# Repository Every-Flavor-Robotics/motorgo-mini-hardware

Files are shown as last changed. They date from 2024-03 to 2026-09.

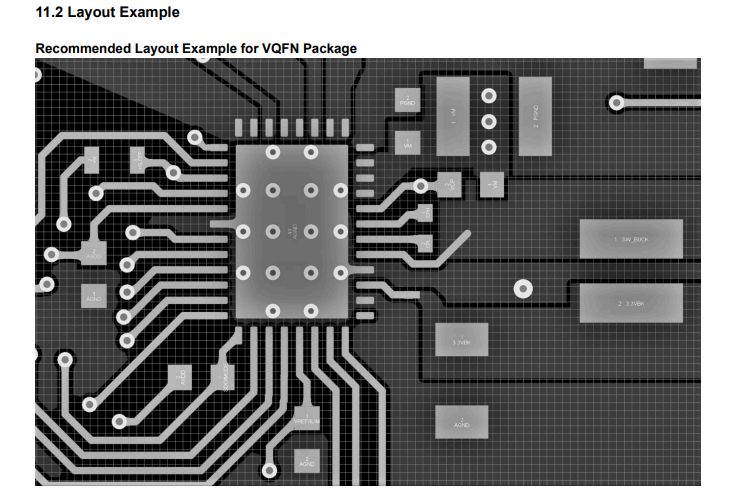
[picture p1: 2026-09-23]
motorgo-gimbus/Pasted image 20250722134249.png

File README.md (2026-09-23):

# motorgo-mini-hardware
## This repo is the home of the hardware revisions for the MotorGo-mini!
### This is a condensed and specialized version of the MotorGo-Mini, featuring:
- Esp32s3 based system, compatible with ESPIDF or Arduino
- Wifi + BT
- Single channel of motor control
- Integrated MT6701 magenetic encoder on back of board
- DRV8316 TI motor controller with low-side current sense
- 3A continous 8A peak FOC motor controls
- RGB LED indicator
- USB PD x2 with power ORing to protect power sources
- 6P JST PH input: 5V-20V
- CAN bus over USB-C (experimental use of sideband signals in USB 3.2+)

### Its still in development, particularly USBPD seems to be malfunctioning.  But checkout the schematics, renders, use example, and photos of the real board!
### Full board Render:
Gimbusv1r2_straight_on

### Example board + motor + rendering:
Gimbusv1r2_exoploded_viewpng

### Top Level Schematic (full color):


### USB Module Sub-Schematic:


### DRV8316 Sub-Schematic:


### RGB indicator:


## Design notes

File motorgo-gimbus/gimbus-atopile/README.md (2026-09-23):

# gimbus

Turn a gimbal motor into a powerful CAN-bus enabled servo with simpleFOC and ESP32

Created by Alexchunlin <alexchunlin@everyflavorrobotics.com>

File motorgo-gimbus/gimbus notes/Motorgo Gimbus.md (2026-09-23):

## This project is to make a small, bussed servo controller compatible with the motorgo ecosystem.
---
### Objectives and context:
1. Many of our previous boards are designed for maximum versatility - but this board is specifically for a small selection of motors.  **Gimbal motors** around the 45mm diameter. 
2. There is an explicit intent to design this board for use in the KineThreads project that is a part of Vivian Shen's research in HRI.  The KineThread project is an exosuit that enables VR and AR haptics by applying forces to the exosuit's joints via tensioned threads.  Each motor on the suit controls a spool of thread and the tension is currently roughly approximated with voltage to each motor.  This project should be able to provide **current control** - increasing the resolution and consistency of tension on the suit.
3. We have not been able to get **USB-PD** reliably working on our boards before and this project will be a test for us in adding that to our ecosystem.
4. Creating this project in atopile will be a new workflow and this relatively simple project should be a good testing ground for this new tool!

### Requirements:
- SimpleFOC compatibility
- Esp32 based for compatibility to the motorgo ecosystem
- Motor controls with voltage range of up to 24V
- Current control on the motor phases, low side or inline is acceptable
- board size must fit within 45mm diameter circle and its maximum height is 10mm
- CAN bus and two physical ports so that a chain of actuators can be made
- USB-PD 5a 20v
- 4 layer board stackup with complete ground plane
- 1 power indicator led in red, 1 motor enabled indicator led in blue, and one neopixel rgb led for  status indication
- two tactile switches for boot and reset 
- magnetic encoder on center of board, opposite side of esp32
- 3 phase motor wire output

### Component Selection
- **Microcontroller: ESP32-S3-WROOM-N8**
	**Reasoning:** A powerful and cost-effective module with integrated Wi-Fi and Bluetooth. It has all the necessary hardware peripherals for this project, including a native CAN controller (TWAI), USB OTG for programming, SPI, and I2C.

- **Motor Driver: DRV8316CR**
	-**Reasoning:** A highly integrated 3-phase motor driver that simplifies the design by including FETs and current sense amplifiers. It supports up to 35V and communicates via SPI for configuration and fault reporting. Its internal buck regulator will not be used to power the ESP32.

- **Buck Regulator: XL1509-3.3E1**
	- **Reasoning:** This switching regulator was chosen to provide a stable 3.3V rail for the entire board. It accepts an input voltage of up to 40V, providing a safe margin, and can deliver up to 2A, which is more than sufficient for the ESP32's peak current draw during radio use.
	- **Implementation Note:** As a non-synchronous converter, this part requires an external Schottky diode for proper operation.

- **USB Power Delivery: HUSB238A-BB001-QN16R (x2)**
	- **Reasoning:** A dedicated USB-PD controller that simplifies power negotiation over USB-C. The design uses two of these ICs, one for each port, to allow for up to 20V @ 5A power delivery. The outputs will be fed into a common power rail via ideal diodes to prevent back-powering.

- **CAN Transceiver: TJA1051T**
	- **Reasoning:** A standard, reliable, 3.3V-compatible CAN transceiver.
	- **Implementation Note:** Each board will feature a 120Ω termination resistor selectable via a jumper or DIP switch. This allows any board to be configured as a termination point if it is at the physical end of the daisy-chain.

- **Encoder: Magntek MT6701**
	- **Reasoning:** A high-resolution magnetic encoder (16,384 counts/rev) compatible with existing software. It communicates via I2C. The MODE pin will be tied to VDD to select I2C operation.

- **USB-C Connectors: XKB_Connectivity_U262_241N_4BV64 (x2)**
	- **Reasoning:** Standard USB-C connectors chosen for their high density and the availability of robust, full-featured cables.

## Circuit & Logic Design
**The board will feature two identical USB-C ports (LEFT and RIGHT) to allow for daisy-chaining of power and data.**

- **Power Delivery:** The CC and VBUS lines from each port are routed to their own dedicated STUSB4500 PD controller.
- **USB Programming MUX:** The D+/D- lines from both ports are routed to a FSUSB42 MUX to allow programming from either port.
- **Switching Logic:** The VBUS from each port will be used to automatically control the MUX's select pin. To prevent a short circuit, a logic gate (e.g., an OR or NOR gate) will be used to combine the signals, creating a priority system where one port takes precedence if both are connected.
- **CAN Bus Topology:** The board will be wired as a pass-through node.
	- The SSTX+/- lines from the LEFT port will be routed directly to the SSTX+/- lines of the RIGHT port.
	- The CAN transceiver's CANH and CANL pins will "tap into" this main bus line with the shortest possible traces.
	- This design maintains a single, continuous bus line through the device, minimizing stubs and ensuring high signal integrity.

### Scratch notes and dev todos:
==**Links to stuff:**==
 > usbc cables: https://www.amazon.com/dp/B0CS64PLTC/?
 > adafruit can dev: https://www.adafruit.com/product/5708?
	 TJA1051T/3/1J
	 > ![[Pasted image 20250721132601.png]]
 > usbc dev: https://www.digikey.com/en/products/detail/stmicroelectronics/EVAL-SCS001V1/10231579?
 > ESP32s3 Tech Ref Manual: https://www.espressif.com/sites/default/files/documentation/esp32-s3_technical_reference_manual_en.pdf
 > ESP32s3 module datasheet: https://www.espressif.com/sites/default/files/documentation/esp32-s3-wroom-1_wroom-1u_datasheet_en.pdf
 > DRV8316 block diagram application:
 > ![[Pasted image 20250722132813.png]]
 ![[Pasted image 20250722134537.png]]
 > ![[Pasted image 20250722134249.png]]

Impedance control for jlc stackup: 90 ohm and 120 ohm lines (CAN and USB)
![[Pasted image 20250723125023.png]]
- CAN TX needs 5v supply - so i had to add a boost conv off of the 3v3 rail, luckily i had designed a good headroom on the 3v3 - here's what I'm adding based on the input current calc:
	- **Power Out:** Pout=5V×70mA=350mW
	- **Power In:** Pin=ηPout=0.85350mW≈412mW
	- **Input Current:** Iin=VinPin=3.3V412mW≈125mA
	- =) C490380, the DIODES PAM2401YPADJ for simplicity even though its overkill

For usb pd protection / power ORing chip is the lm73100 
- VIN(UV) = 1.22V * (270kΩ + 100kΩ) / 100kΩ = 4.514V
- VIN(OV) = 1.22V * (160kΩ + 10kΩ) / 10kΩ = 20.74V
- isense from ideal diode to get board current:
	- R_imon = V_imon /G* I_imon 
		- R_imon = 1.65 Kohm resistor
		- set ESP32 to ADC_ATTEN_DB_6 (0mv -1750mv)
	- zener diode choose for 1.8v to clamp spikes

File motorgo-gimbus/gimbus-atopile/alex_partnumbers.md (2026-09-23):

encoder : MT6701QT-STD - C2913974
mcu : ESP32-S3-WROOM-1-N8 - C2913198
usbc thru : U262-241N-4BV64 - C388660
motor driver: DRV8316CRRGFR - C5447274
3v3 buck : SXL1509-3.3E1 - C33960106
6p jstph : S6B-PH-SM4-TB(LF)(SN) - C2845446
CAN TX : TJA1051TK/3/1J - C2875699
USB MUX: FSUSB42UMX - C42370490
usbpd : STUSB4500QTR - C2678061
inductor_buck : C2929441
schottkey : C8598
schottky_tiny : C2923958

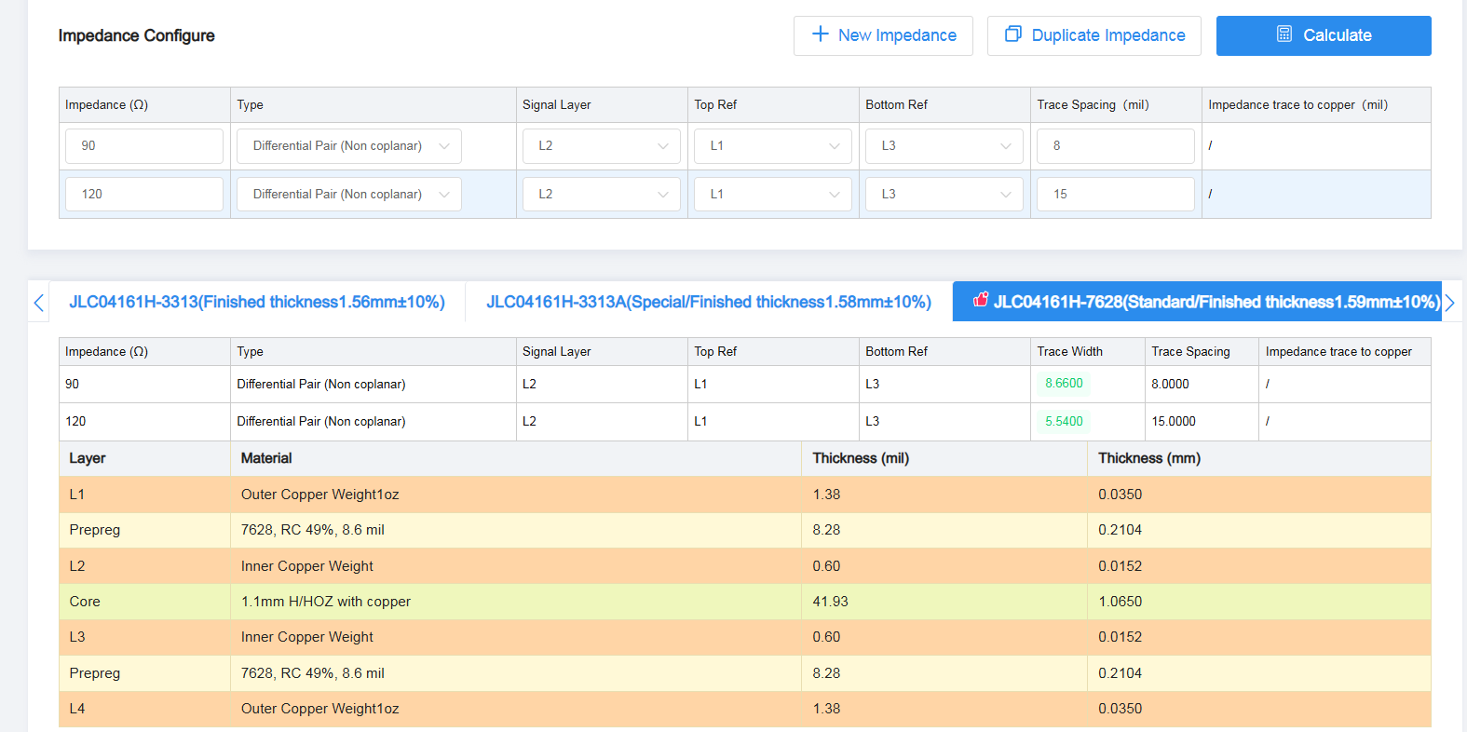
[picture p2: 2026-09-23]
motorgo-gimbus/Pasted image 20250723125023.png

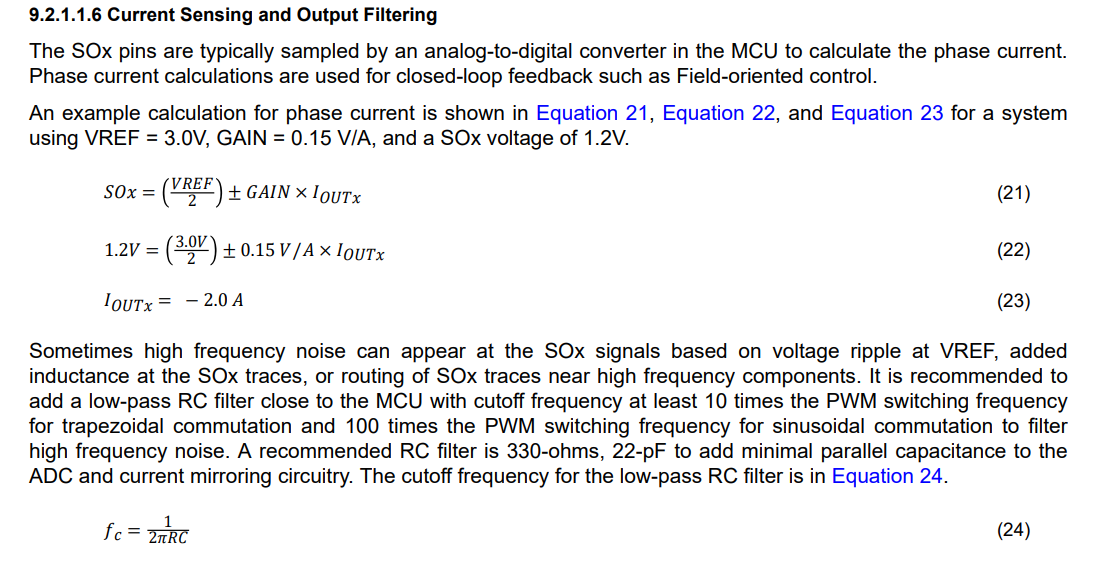
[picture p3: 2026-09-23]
motorgo-gimbus/Pasted image 20250722134537.png

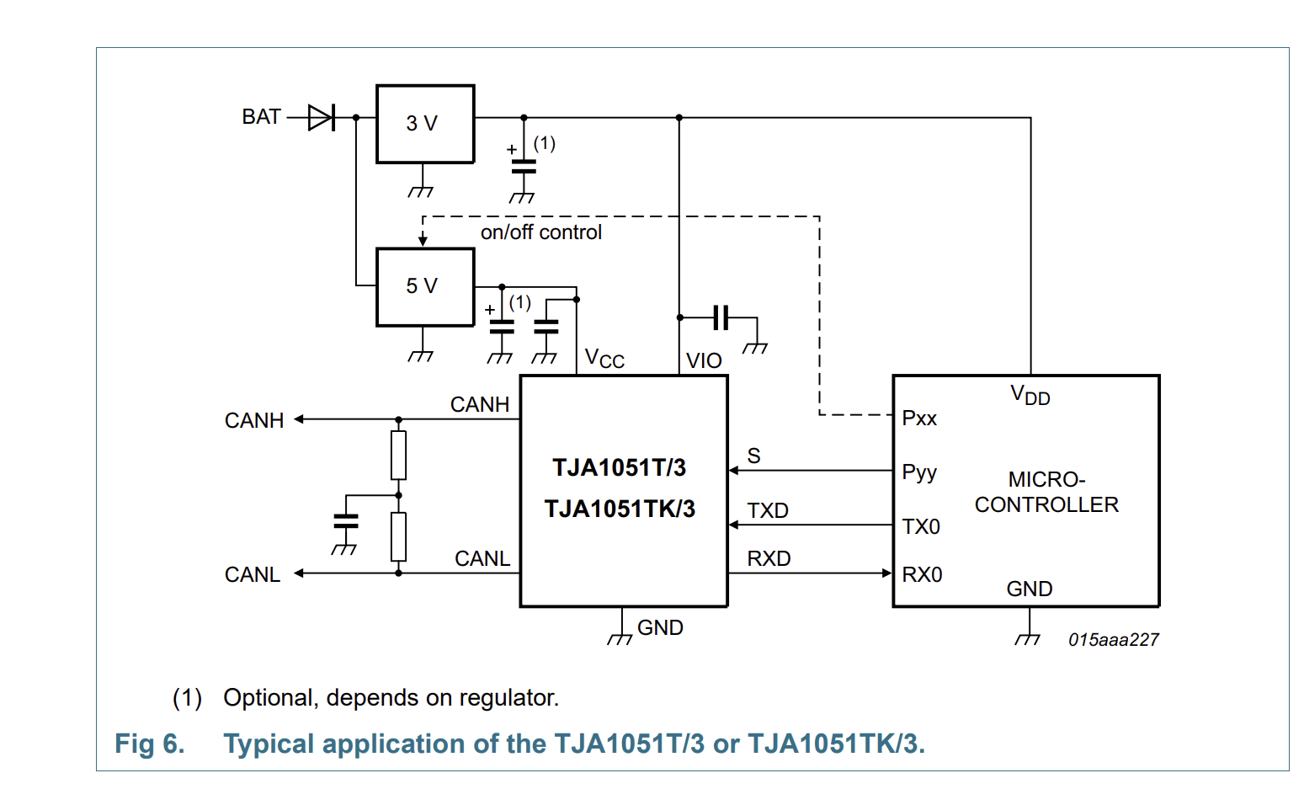
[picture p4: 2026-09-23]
motorgo-gimbus/gimbus notes/Pasted image 20250721132601.png

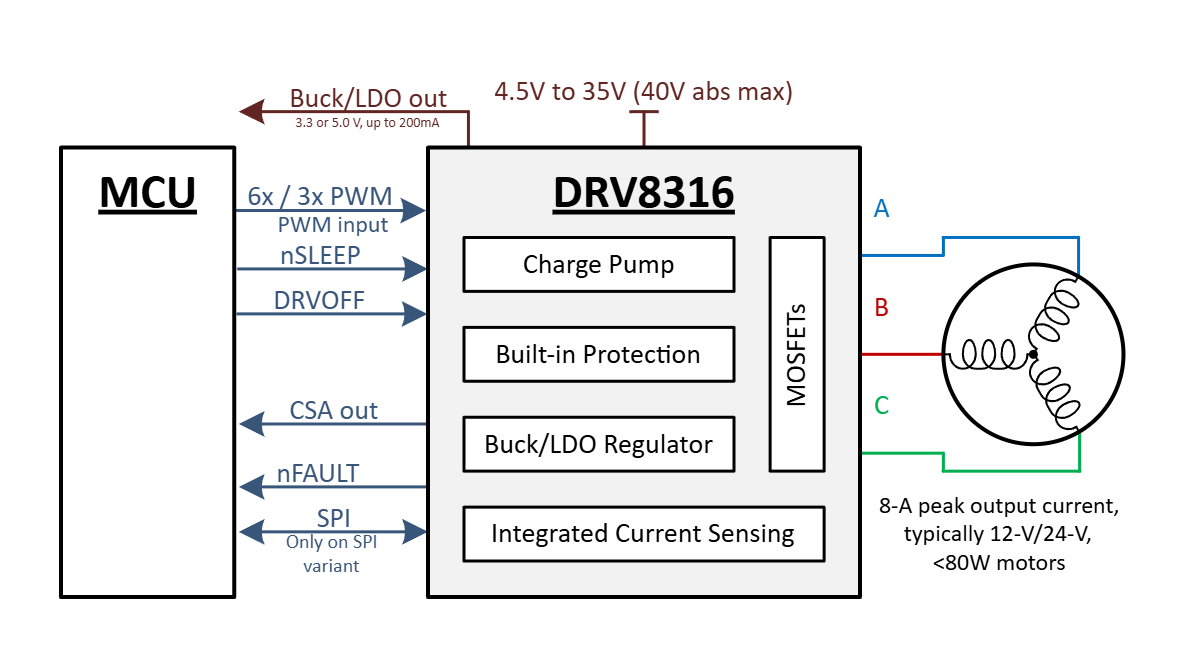
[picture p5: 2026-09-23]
motorgo-gimbus/Pasted image 20250722132813.png

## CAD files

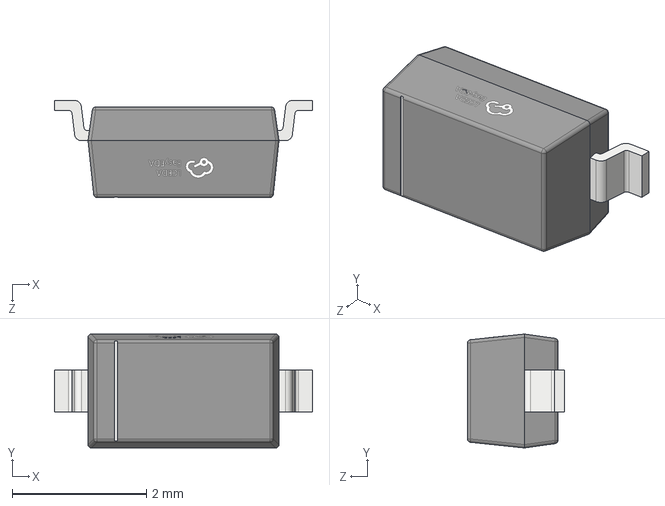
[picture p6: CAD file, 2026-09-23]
motorgo-gimbus/gimbus-atopile/parts/Changjiang_Electronics_Tech_B5819W_SL/SOD-123_L2.7-W1.6-LS3.7-RD-1.step
3.85 x 1.70 x 1.45 mm

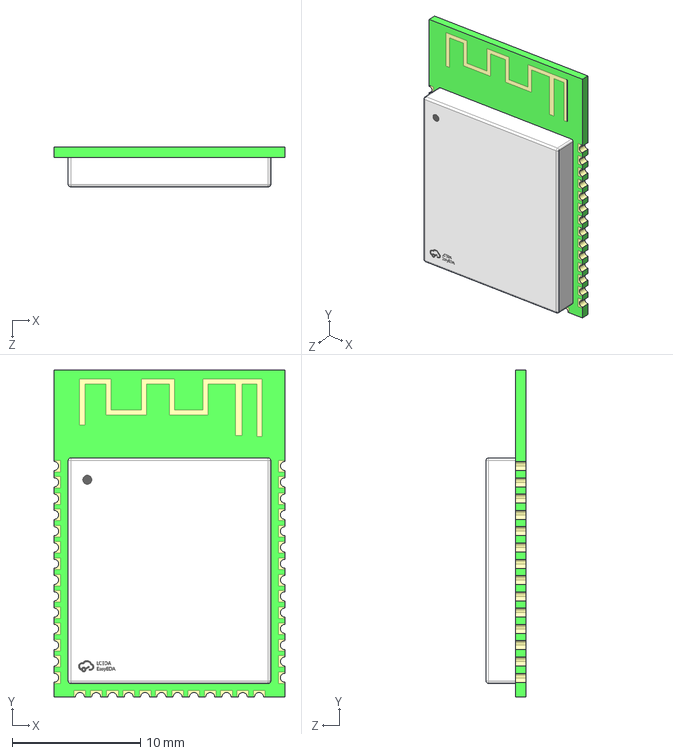
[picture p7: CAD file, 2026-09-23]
motorgo-gimbus/gimbus-atopile/parts/Espressif_Systems_ESP32_S3_WROOM_1_N8/WIFIM-SMD_ESP32-S3-WROOM-1-N8.STEP
18.0 x 25.5 x 3.12 mm

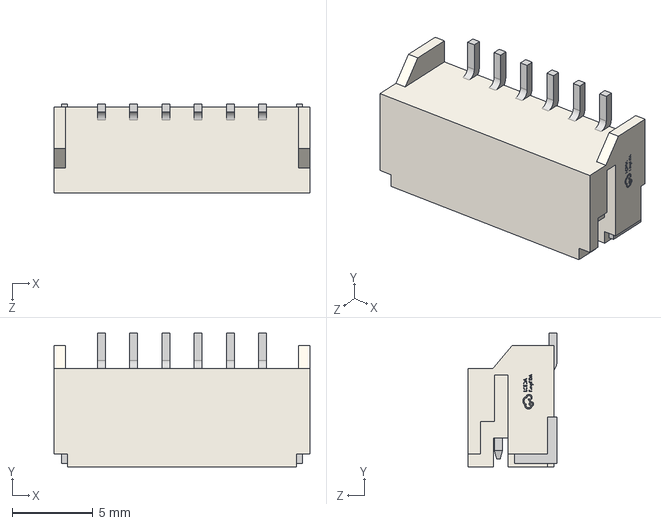
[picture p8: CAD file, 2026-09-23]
motorgo-gimbus/gimbus-atopile/parts/HCTL_HC_PH_6AWT/CONN-SMD_6P-P2.00_HCTL_HC-PH-6AWT.step
15.9 x 8.30 x 5.55 mm

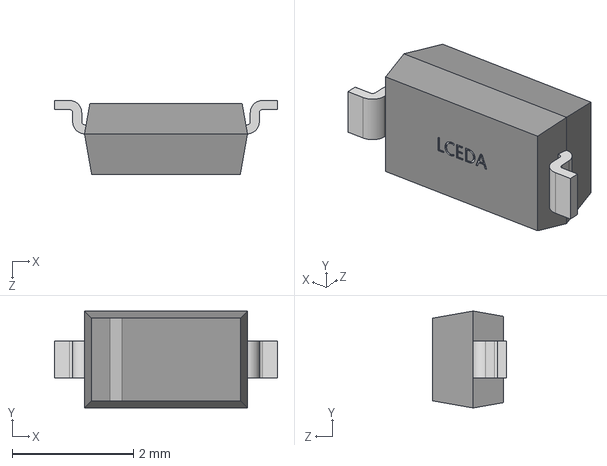
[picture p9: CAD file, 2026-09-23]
motorgo-gimbus/gimbus-atopile/parts/Jiangsu_Changjing_Electronics_Technology_Co___Ltd_DSS34/SOD-123_L2.8-W1.8-LS3.7-RD.STEP
3.68 x 1.60 x 1.22 mm

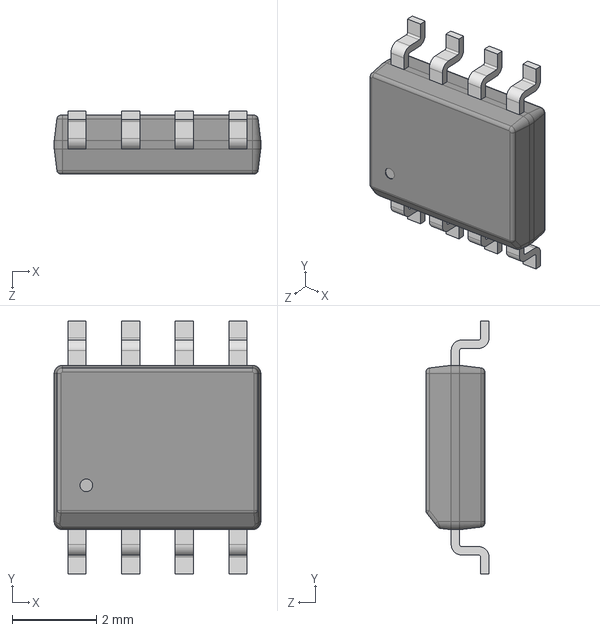
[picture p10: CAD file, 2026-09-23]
motorgo-gimbus/gimbus-atopile/parts/JSMSEMI_SXL1509_3_3E1/SOP-8_L4.9-W3.9-P1.27-LS6.0-BL-1.STEP
4.90 x 6.00 x 1.50 mm

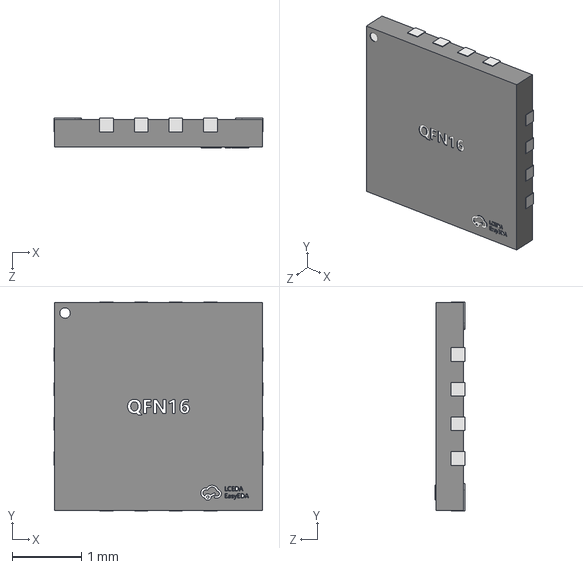
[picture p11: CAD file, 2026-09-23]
motorgo-gimbus/gimbus-atopile/parts/Magn_Tek_MT6701QT_STD/QFN-16_L3.0-W3.0-H0.9-P0.50.step
3.02 x 3.02 x 0.43 mm

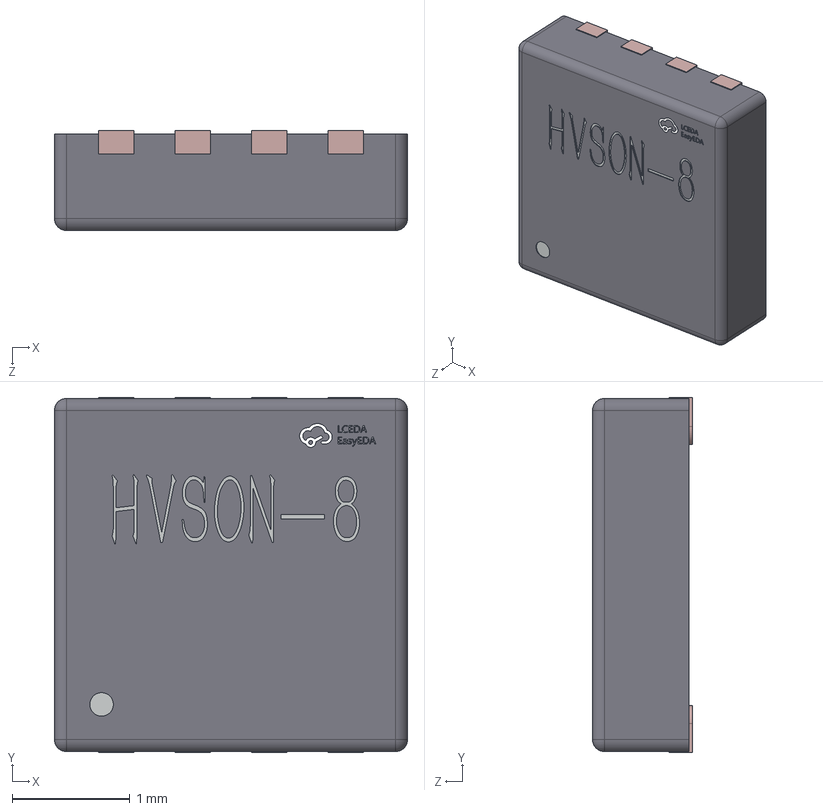
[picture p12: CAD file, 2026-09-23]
motorgo-gimbus/gimbus-atopile/parts/NXP_Semicon_TJA1051TK_3_1J/HVSON-8_L3.0-W3.0-H0.85-P0.65-BL-EP.step
3.00 x 3.02 x 0.851 mm

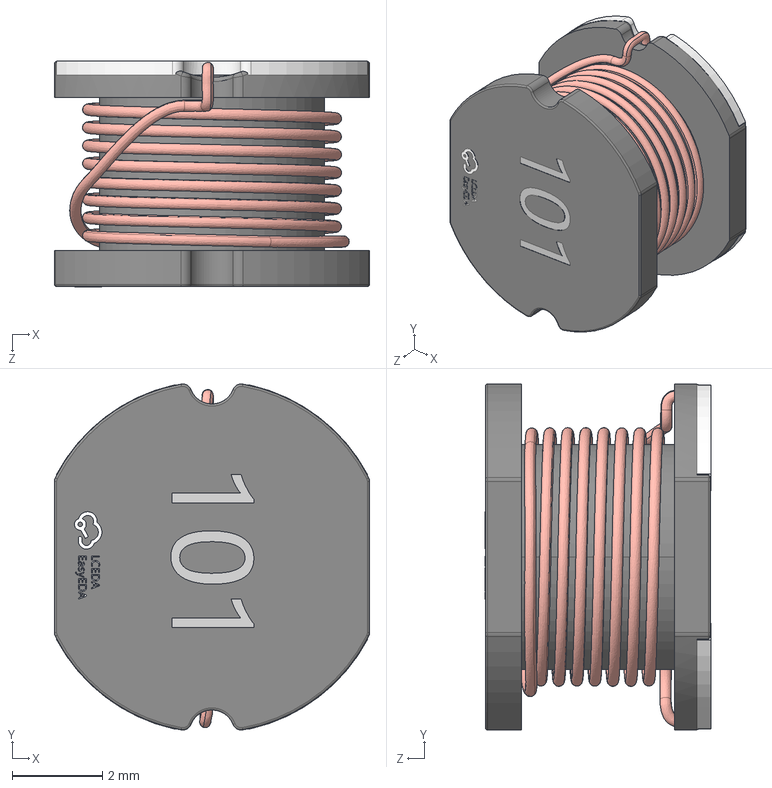
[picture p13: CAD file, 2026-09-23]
motorgo-gimbus/gimbus-atopile/parts/SHOU_HAN_CY75_47UH/IND-SMD_L7.8-W7.0-H5.0-0.705.step
7.00 x 7.68 x 5.02 mm

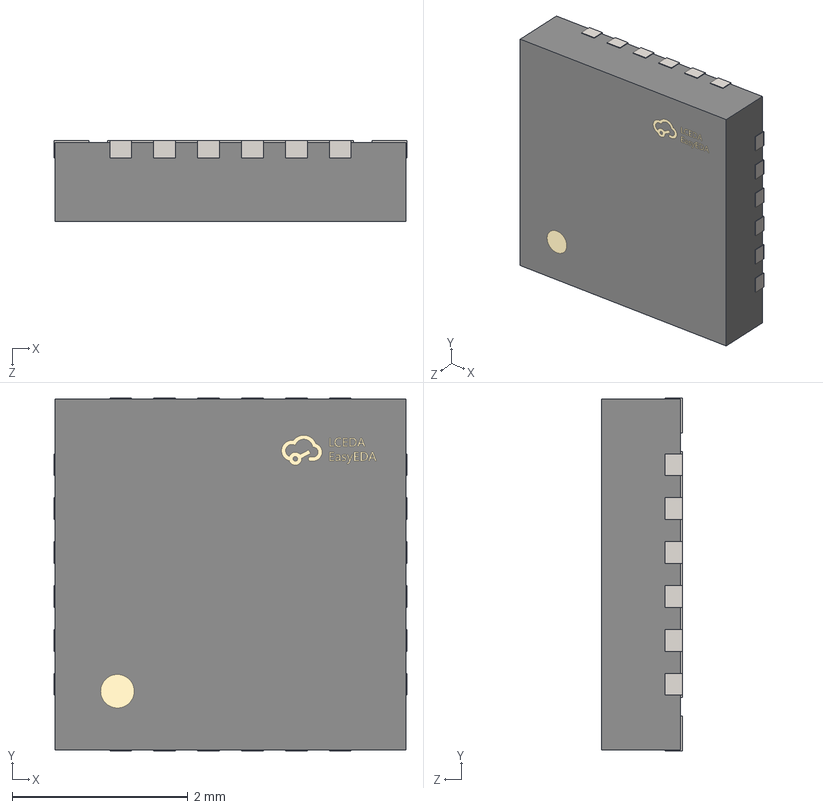
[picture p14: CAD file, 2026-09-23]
motorgo-gimbus/gimbus-atopile/parts/STMicroelectronics_STUSB4500QTR/57.STEP
4.02 x 4.02 x 0.92 mm

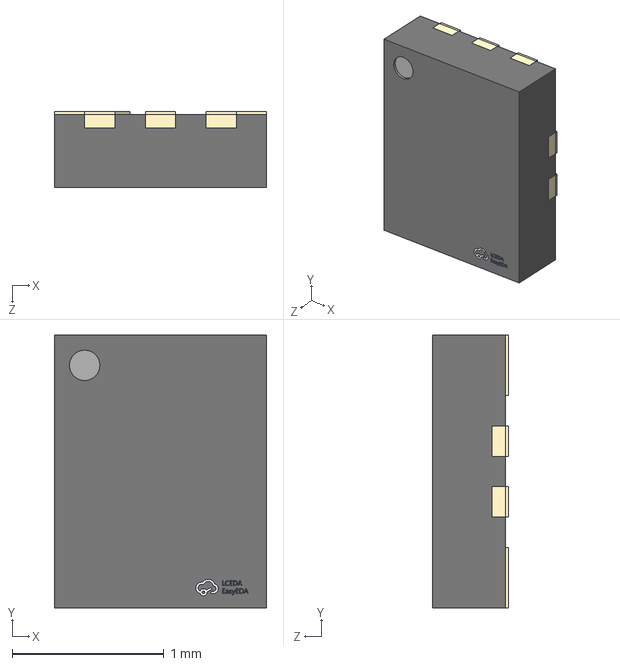
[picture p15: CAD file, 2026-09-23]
motorgo-gimbus/gimbus-atopile/parts/TECH_PUBLIC_FSUSB42UMX_TP/XQFN-10_L1.8-W1.4-H0.5-P0.40-TL.step
1.40 x 1.80 x 0.501 mm

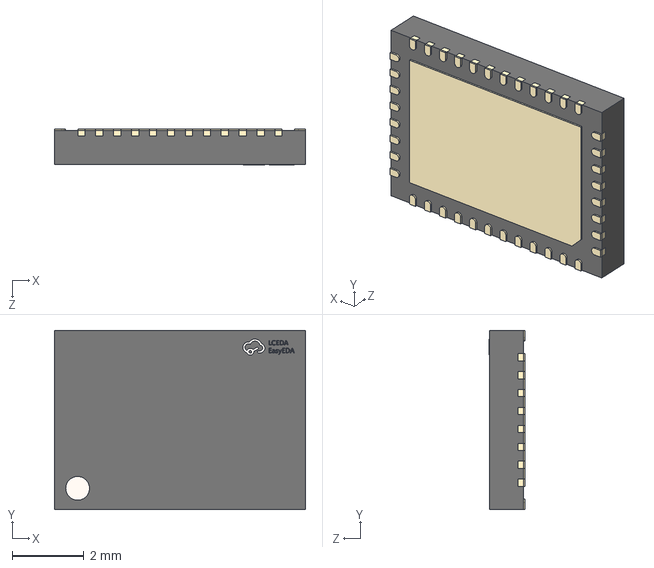
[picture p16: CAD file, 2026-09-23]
motorgo-gimbus/gimbus-atopile/parts/Texas_Instruments_DRV8316CRRGFR/VQFN-40_L7.0-W5.0-P0.50-BL-EP5.7.STEP
7.00 x 5.00 x 1.01 mm

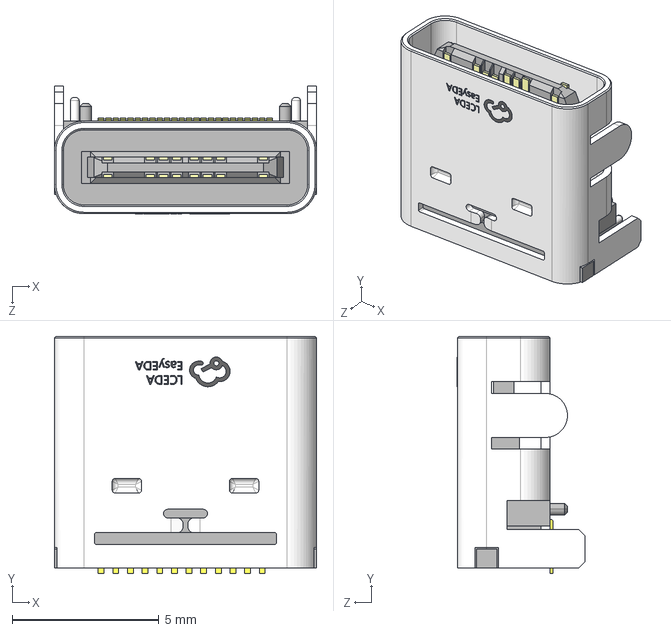
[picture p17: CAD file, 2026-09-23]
motorgo-gimbus/gimbus-atopile/parts/XKB_Connectivity_U262_241N_4BV64/USB-C-SMD_TYC-324G.step
8.94 x 8.10 x 4.35 mm

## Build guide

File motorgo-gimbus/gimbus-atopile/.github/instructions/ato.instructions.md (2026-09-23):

---
description: ato is a declarative DSL to design electronics (PCBs) with.
applyTo: *.ato, ato.yaml
---

ato is a declarative DSL to design electronics (PCBs) with.
It is part of the atopile project.
Atopile is run by the vscode/cursor/windsurf extension.
The CLI (which is invoked by the extension) actually builds the project.

# Not available in ato

- if statements
- while loops
- functions (calls or definitions)
- classes
- objects
- exceptions
- generators

# Ato Syntax

ato sytax is heavily inspired by Python, but fully declarative.
ato thus has no procedural code, and no side effects.

## Examples of syntax

```ato
#pragma text
#pragma func("X")
# enable for loop syntax feature:
#pragma experiment("FOR_LOOP)

# --- Imports ---
# Standard import (newline terminated)
import ModuleName

# Import with multiple modules (newline terminated)
import Module1, Module2.Submodule

# Import from a specific file/source (newline terminated)
from "path/to/source.ato" import SpecificModule

# Multiple imports on one line (semicolon separated)
import AnotherModule; from "another/source.ato" import AnotherSpecific

# Deprecated import form (newline terminated)
# TODO: remove when unsupported
import DeprecatedModule from "other/source.ato"

# --- Top-level Definitions and Statements ---

pass
pass;

"docstring-like statement"
"docstring-like statement";

top_level_var = 123

# Compound statement
pass; another_var = 456; "another docstring"

# Block definitions
component MyComponent:
    # Simple statement inside block (newline terminated)
    pass

    # Multiple simple statements on one line (semicolon separated)
    pass; internal_flag = True

module AnotherBaseModule:
    pin base_pin
    base_param = 10

interface MyInterface:
    pin io

module DemoModule from AnotherBaseModule:
    # --- Declarations ---
    pin p1              # Pin declaration with name
    pin 1               # Pin declaration with number
    pin "GND"           # Pin declaration with string
    signal my_signal    # Signal definition
    a_field: AnotherBaseModule      # Field declaration with type hint

    # --- Assignments ---
    # Newline terminated:
    internal_variable = 123

    # Semicolon separated on one line:
    var_a = 1; var_b = "string"

    # Cumulative assignment (+=, -=) - Newline terminated
    value = 1
    value += 1; value -= 1

    # Set assignment (|=, &=) - Newline terminated
    flags |= 1; flags &= 2

    # --- Connections ---
    p1 ~ base_pin
    mif ~> bridge
    mif ~> bridge ~> bridge
    mif ~> bridge ~> bridge ~> mif
    bridge ~> mif
    mif <~ bridge
    mif <~ bridge <~ bridge
    mif <~ bridge <~ bridge <~ mif
    bridge <~ mif

    # Semicolon separated on one line:
    p_multi1 ~ my_signal; p_multi2 ~ sig_multi1

    # --- Retyping ---
    instance.x -> AnotherBaseModule

    # --- Instantiation ---
    instance = new MyComponent
    container = new MyComponent[10]
    templated_instance_a = new MyComponent
    templated_instance_b = new MyComponent<int_=1>
    templated_instance_c = new MyComponent<float_=2.5>
    templated_instance_d = new MyComponent<string_="hello">
    templated_instance_e = new MyComponent<int_=1, float_=2.5, string_="hello">
    templated_instance_f = new MyComponent<int_=1, float_=2.5, string_="hello", bool_=True>

    # Semicolon separated instantiations (via assignment):
    inst_a = new MyComponent; inst_b = new AnotherBaseModule

    # --- Traits ---
    trait trait_name
    trait trait_name<int_=1>
    trait trait_name<float_=2.5>
    trait trait_name<string_="hello">
    trait trait_name<bool_=True>
    trait trait_name::constructor
    trait trait_name::constructor<int_=1>

    # Semicolon separated on one line:
    trait TraitA; trait TraitB::constructor; trait TraitC<arg_=1>

    # --- Assertions ---
    assert x > 5V
    assert x < 10V
    assert 5V < x < 10V
    assert x >= 5V
    assert x <= 10V
    assert current within 1A +/- 10mA
    assert voltage within 1V +/- 10%
    assert resistance is 1kohm to 1.1kohm

    # Semicolon separated on one line:
    assert x is 1V; assert another_param is 2V

    # --- Loops ---
    for item in container:
        item ~ p1

    # For loop iterating over a slice
    for item in container[0:4]:
        pass
        item.value = 1; pass

    # For loop iterating over a list literal of field references
    for ref in [p1, x.1, x.GND]:
        pass

    # --- References and Indexing ---
    # Reference with array index assignment
    array_element = container[3]

    # --- Literals and Expressions ---
    # Integer
    int_val = 100
    neg_int_val = -50
    hex_val = 0xF1
    bin_val = 0b10
    oct_val = 0o10
    # Float
    float_val = 3.14
    # Physical quantities
    voltage: V = 5V
    resistance: ohm = 10kohm
    capacitance: F = 100nF
    # Bilateral tolerance
    tolerance_val = 1kohm +/- 10%
    tolerance_abs = 5V +/- 500mV
    tolerance_explicit_unit = 10A +/- 1A
    # Bounded quantity (range)
    voltage_range = 3V to 3.6V
    # Boolean
    is_enabled = True
    is_active = False
    # String
    message = "Hello inside module"

    # Arithmetic expressions
    sum_val = 1 + 2
    diff_val = 10 - 3ohm
    prod_val = 5 * 2mA
    div_val = 10V / 2kohm # Results in current
    power_val = 2**3
    complex_expr = (5 + 3) * 2 - 1
    flag_check = state | MASK_VALUE

    # Comparisons
    assert voltage within voltage_range
    assert length <= 5mm
    assert height >= 2mm

# --- Multi-line variations ---
pass; nested_var=1; another=2

complex_assignment = (
    voltage + resistance
    * capacitance
)

```

## G4 Grammar

```g4
parser grammar AtoParser;

options {
	superClass = AtoParserBase;
	tokenVocab = AtoLexer;
}

file_input: (NEWLINE | stmt)* EOF;

pragma_stmt: PRAGMA;

stmt: simple_stmts | compound_stmt | pragma_stmt;
simple_stmts:
	simple_stmt (SEMI_COLON simple_stmt)* SEMI_COLON? NEWLINE;
simple_stmt:
	import_stmt
	| dep_import_stmt
	| assign_stmt
	| cum_assign_stmt
	| set_assign_stmt
	| connect_stmt
	| directed_connect_stmt
	| retype_stmt
	| pin_declaration
	| signaldef_stmt
	| assert_stmt
	| declaration_stmt
	| string_stmt
	| pass_stmt
	| trait_stmt;

compound_stmt: blockdef | for_stmt;

blockdef: blocktype name blockdef_super? COLON block;
// TODO @v0.4 consider ()
blockdef_super: FROM type_reference;
// TODO @v0.4 consider removing component (or more explicit code-as-data)
blocktype: (COMPONENT | MODULE | INTERFACE);
block: simple_stmts | NEWLINE INDENT stmt+ DEDENT;

// TODO: @v0.4 remove the deprecated import form
dep_import_stmt: IMPORT type_reference FROM string;
import_stmt: (FROM string)? IMPORT type_reference (
		COMMA type_reference
	)*;

declaration_stmt: field_reference type_info;
field_reference_or_declaration:
	field_reference
	| declaration_stmt;
assign_stmt: field_reference_or_declaration '=' assignable;
cum_assign_stmt:
	field_reference_or_declaration cum_operator cum_assignable;
// TODO: consider sets cum operator
set_assign_stmt:
	field_reference_or_declaration (OR_ASSIGN | AND_ASSIGN) cum_assignable;
cum_operator: ADD_ASSIGN | SUB_ASSIGN;
cum_assignable: literal_physical | arithmetic_expression;

assignable:
	string
	| new_stmt
	| literal_physical
	| arithmetic_expression
	| boolean_;

retype_stmt: field_reference ARROW type_reference;

directed_connect_stmt
	: bridgeable ((SPERM | LSPERM) bridgeable)+; // only one type of SPERM per stmt allowed. both here for better error messages
connect_stmt: mif WIRE mif;
bridgeable: connectable;
mif: connectable;
connectable: field_reference | signaldef_stmt | pindef_stmt;

signaldef_stmt: SIGNAL name;
pindef_stmt: pin_stmt;
pin_declaration: pin_stmt;
pin_stmt: PIN (name | number_hint_natural | string);

new_stmt: NEW type_reference ('[' new_count ']')? template?;
new_count: number_hint_natural;

string_stmt:
	string; // the unbound string is a statement used to add doc-strings

pass_stmt:
	PASS; // the unbound string is a statement used to add doc-strings

list_literal_of_field_references:
	'[' (field_reference (COMMA field_reference)* COMMA?)? ']';

iterable_references:
	field_reference slice?
	| list_literal_of_field_references;

for_stmt: FOR name IN iterable_references COLON block;

assert_stmt: ASSERT comparison;

trait_stmt
	: TRAIT type_reference (DOUBLE_COLON constructor)? template?; // TODO: move namespacing to type_reference
constructor: name;
template: '<' (template_arg (COMMA template_arg)* COMMA?)? '>';
template_arg: name ASSIGN literal;

// Comparison operators --------------------
comparison: arithmetic_expression compare_op_pair+;

compare_op_pair:
	lt_arithmetic_or
	| gt_arithmetic_or
	| lt_eq_arithmetic_or
	| gt_eq_arithmetic_or
	| in_arithmetic_or
	| is_arithmetic_or;

lt_arithmetic_or: LESS_THAN arithmetic_expression;
gt_arithmetic_or: GREATER_THAN arithmetic_expression;
lt_eq_arithmetic_or: LT_EQ arithmetic_expression;
gt_eq_arithmetic_or: GT_EQ arithmetic_expression;
in_arithmetic_or: WITHIN arithmetic_expression;
is_arithmetic_or: IS arithmetic_expression;

// Arithmetic operators --------------------

arithmetic_expression:
	arithmetic_expression (OR_OP | AND_OP) sum
	| sum;

sum: sum (PLUS | MINUS) term | term;

term: term (STAR | DIV) power | power;

power: functional (POWER functional)?;

functional: bound | name '(' bound+ ')';

bound: atom;

// Primary elements ----------------

slice:
	'[' (slice_start? COLON slice_stop? (COLON slice_step?)?)? ']'
	// else [::step] wouldn't match
	| '[' ( DOUBLE_COLON slice_step?) ']';
slice_start: number_hint_integer;
slice_stop: number_hint_integer;
slice_step: number_hint_integer;

atom: field_reference | literal_physical | arithmetic_group;

arithmetic_group: '(' arithmetic_expression ')';

literal_physical:
	bound_quantity
	| bilateral_quantity
	| quantity;

bound_quantity: quantity TO quantity;
bilateral_quantity: quantity PLUS_OR_MINUS bilateral_tolerance;
quantity: number name?;
bilateral_tolerance: number_signless (PERCENT | name)?;

key: number_hint_integer;
array_index: '[' key ']';

// backwards compatibility for A.1
pin_reference_end: DOT number_hint_natural;
field_reference_part: name array_index?;
field_reference:
	field_reference_part (DOT field_reference_part)* pin_reference_end?;
type_reference: name (DOT name)*;
// TODO better unit
unit: name;
type_info: COLON unit;
name: NAME;

// Literals
literal: string | boolean_ | number;

string: STRING;
boolean_: TRUE | FALSE;
number_hint_natural: number_signless;
number_hint_integer: number;
number: (PLUS | MINUS)? number_signless;
number_signless: NUMBER;
```

# Most used library modules/interfaces (api of them)

```ato
interface Electrical:
    pass

interface ElectricPower:
    hv = new Electrical
    lv = new Electrical

module Resistor:
    resistance: ohm
    max_power: W
    max_voltage: V
    unnamed = new Electrical[2]

module Capacitor:
    capacitance: F
    max_voltage: V
    unnamed = new Electrical[2]

interface I2C:
    scl = new ElectricLogic
    sda = new ElectricLogic
    frequency: Hz
    address: dimensionless

interface ElectricLogic:
    line = new Electrical
    reference = new ElectricPower
```

For the rest use the atopile MCP server 
- `get_library_interfaces` to list interfaces
- `get_library_modules` to list modules
- `inspect_library_module_or_interface` to inspect the code

# Ato language features

## experimental features

Enable with `#pragma experiment("BRIDGE_CONNECT")`
BRIDGE_CONNECT: enables `p1 ~> resistor ~> p2` syntax
FOR_LOOP: enables `for item in container: pass` syntax
TRAITS: enables `trait trait_name` syntax
MODULE_TEMPLATING: enables `new MyComponent<param=literal>` syntax

## modules, interfaces, parameters, traits

A block is either a module, interface or component.
Components are just modules for code-as-data.
Interfaces describe a connectable interface (e.g Electrical, ElectricPower, I2C, etc).
A module is a block that can be instantiated.
Think of it as the ato equivalent of a class.
Parameters are variables for numbers and they work with constraints.
E.g `resistance: ohm` is a parameter.
Constrain with `assert resistance within 10kohm +/- 10%`.
It's very important to use toleranced values for parameters.
If you constrain a resistor.resistance to 10kohm there won't be a single part found because that's a tolerance of 0%.

Traits mark a module to have some kind of functionality that can be used in other modules.
E.g `trait has_designator_prefix` is the way to mark a module to have a specific designator prefix that will be used in the designator field in the footprint.

## connecting

You can only connect interfaces of the same type.
`resistor0.unnamed[0] ~ resistor0.unnamed[0]` is the way to connect two resistors in series.
If a module has the `can_bridge` trait you can use the sperm operator `~>` to bridge the module.
`led.anode ~> resistor ~> power.hv` connects the anode in series with the resistor and then the resistor in series with the high voltage power supply.

## for loop syntax

`for item in container: pass` is the way to iterate over a container.

# Ato CLI

## How to run

You run ato commands through the MCP tool.

## Packages

Packages can be found on the ato registry.
To install a package you need to run `ato add <PACKAGE_NAME>`.
e.g `ato install atopile/addressable-leds`
And then can be imported with `from "atopile/addressable-leds/sk6805-ec20.ato" import SK6805_EC20_driver`.
And used like this:

```ato
module MyModule:
    led = new SK6805_EC20_driver
```

## Footprints & Part picking

Footprint selection is done through the part choice (`ato create part` auto-generates ato code for the part).
The `pin` keyword is used to build footprint pinmaps so avoid using it outside of `component` blocks.
Preferrably use `Electrical` interface for electrical interfaces.
A lot of times it's actually `ElectricLogic` for things like GPIOs etc or `ElectricPower` for power supplies.

Passive modules (Resistors, Capacitors) are picked automatically by the constraints on their parameters.
To constrain the package do e.g `package = "0402"`.
To explictly pick a part for a module use `lcsc = "<LCSC_PART_NUMBER>"`.

# Creating a package

Package generation process:

Review structure of other pacakges.

1. Create new Directory in 'packages/packages' with naming convention '<vendor>-<device>' eg 'adi-adau145x'
2. create an ato.yaml file in the new directory with the following content:

```yaml
requires-atopile: '^0.9.0'

paths:
    src: '.'
    layout: ./layouts

builds:
    default:
        entry: <device>.ato:<device>_driver
    example:
        entry: <device>.ato:Example
```

3. Create part using tool call 'search_and_install_jlcpcb_part'
4. Import the part into the <device>.ato file
5. Read the datasheet for the device
6. Find common interfaces in the part eg I2C, I2S, SPI, Power

7. Create interfaces and connect them

power interfaces:
power*<name> = new ElectricPower
power*<name>.required = True # If critical to the device
assert power\*<name>.voltage within <minimum*operating_voltage>V to <maximum_operating_voltage>V
power*<name>.vcc ~ <device>.<vcc pin>
power\_<name>.gnd ~ <device>.<gnd pin>

i2c interfaces:
i2c = new I2C
i2c.scl.line ~ <device>.<i2c scl pin>
i2c.sda.line ~ <device>.<i2c sda pin>

spi interfaces:
spi = new SPI
spi.sclk.line ~ <device>.<spi sclk pin>
spi.mosi.line ~ <device>.<spi mosi pin>
spi.miso.line ~ <device>.<spi miso pin>

8. Add decoupling capacitors

looking at the datasheet, determine the required decoupling capacitors

eg: 2x 100nF 0402:

power_3v3 = new ElectricPower

# Decoupling power_3v3

power_3v3_caps = new Capacitor[2]
for capacitor in power_3v3_caps:
capacitor.capacitance = 100nF +/- 20%
capacitor.package = "0402"
power_3v3.hv ~> capacitor ~> power_3v3.lv

9. If device has pin configurable i2c addresses

If format is: <n x fixed address bits><m x pin configured address bits>
use addressor module:

- Use `Addressor<address_bits=N>` where **N = number of address pins**.
- Connect each `address_lines[i].line` to the corresponding pin, and its `.reference` to a local power rail.
- Set `addressor.base` to the lowest possible address and `assert addressor.address is i2c.address`.

10. Create a README.md

# <Manufacturer> <Manufacturer part number> <Short description>

## Usage

```ato
<copy in example>

```

## Contributing

Contributions to this package are welcome via pull requests on the GitHub repository.

## License

This atopile package is provided under the [MIT License](https://opensource.org/license/mit/).

11. Connect high level interfaces directly in example:

eg:

i2c = new I2C
power = new ElectricPower
sensor = new Sensor

i2c ~ sensor.i2c
power ~ sensor.power_3v3

# Additional Notes & Gotchas (generic)

- Multi-rail devices (VDD / VDDIO, AVDD / DVDD, etc.)

    - Model separate `ElectricPower` interfaces for each rail (e.g. `power_core`, `power_io`).
    - Mark each `.required = True` if the device cannot function without it, and add voltage assertions per datasheet.

- Optional interfaces (SPI vs I²C)

    - If the device supports multiple buses, pick one for the initial driver. Leave unused bus pins as `ElectricLogic` lines or expose a second interface module later.

- Decoupling guidance

    - If the datasheet shows multiple caps, model the **minimum required** set so the build passes; you can refine values/packages later.

- File / directory layout recap
    - `<vendor>-<device>/` – package root
    - `ato.yaml` – build manifest (include `default` **and** `example` targets)
    - `<device>.ato` – driver + optional example module
    - `parts/<MANUFACTURER_PARTNO>/` – atomic part + footprint/symbol/step files

These tips should prevent common "footprint not found", "pin X missing", and build-time path errors when you add new devices.

# Vibe coding a project

If the user gives you high level description of the project, use the following guide:

# How LLMs can design electronics:

#1 Rule: USE THE TOOLS. If the tools dont work, dont freak out, you are probably using them wrong. Ask for help if you get stuck.

Top level design

1. Research available packages relevant to the user requests using 'find_packages'
2. Inspect promising packages using 'inspect_package'
3. Propose packages to use for project and architucture to user, revise if needed
4. Install needed packages using 'install_package'
5. Import packages into main file
6. Create instances of packages in main module

## Power

1. Review for each package the required voltage and current (current may not be provided, use judement if nessesary)
2. Determine the power rails that need to be generated and a suitable tollerance (typically ~3-5% is acceptable)
3. Determine the input power source, typically a battery, USB connector or other power connector (eg XT30) and install relevant package
4. Find suitable regulators:
   a) if input voltage > required voltage and current is low, use an LDO package
   b) if input voltage > required voltage and current is high, use buck converter
   c) if input votlage < required voltage, use a boost converter
   d) if input voltage can be both less than or greater than input voltage, use buck boost (eg battery powered device that needs 3v3)
5. If battery powered, add charger package

Typical power architucture example with LDO:

- USB input power
- Low current output (eg microcontroller)

from "atopile/ti-tlv75901/ti-tlv75901.ato" import TLV75901_driver
from "atopile/usb-connectors/usb-connectors.ato" import USBCConn

module App:

    # Rails
    power_5v = new Power
    power_3v3 = new Power

    # Components
    ldo = new TLV75901_driver
    usb_connector = new USBCConn

    # Connections
    usb_connector.power ~ power_vbus
    power_vbus ~> ldo ~> power_3v3

## Communicaions

1. Review packages required interfaces, typically i2c, spi or ElectricLogics
2. Find suitable pins on the controller, typically a microcontroller or Linux SOC
3. Connect interfaces eg micro.i2c[0] ~ sensor.i2c

## Development process notes

- After making changes, be sure to use 'build_project' to update the PCB
- Builds will often generate errors/warnings, these should be reviewed and fixed
- Prioritize pacakges from 'atopile' over other packages

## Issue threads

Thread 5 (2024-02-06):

find buttons that are easier to press

alexchunlin, 2024-02-06:
current buttons have failed user testing (ie. me and swap have a hard time pressing them) find a cost effective alternative ideally as a drop in replacement for the BOM

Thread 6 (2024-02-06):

replace 6 pin commutation with 3 pin

alexchunlin, 2024-02-06:
if the TMC6300 motor controllers are to be kept for further design iterations, the 6 gpio control over the half bridges is unnecessary.  It would be better for majority of users to see extra gpio pins (we could have 6 MORE gpio) by placing some signal inverting transistors in the motor control section of the design.

* Instead of 1 half bridge requiring 2 gpio outputs ( timed to avoid shoot-through ), use 1 gpio to trigger an inverted and non-inverted signal that both go to the corresponding halfbridge.

* the logic gates must be chosen such that the timing does not cause shoot-through.

* the cost should be minimized

* the footprint must not change

* the extra GPIO should then be routed appropriately for pinheader or alternative use

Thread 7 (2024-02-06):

Add "servo" style power busses for GPIO line on right.

alexchunlin, 2024-02-06:
with minor re-arrangement. the board could support servos as a plug-n-play solution.

* all gpio pins on the right side of the board should have a 5v and gnd pin header next to them to allow for this.

* assume power management is capable of this and only change layout to close this issue.

* board outline must not change.

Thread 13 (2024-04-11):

EncoderGo does not have basic functionality broken out

alexchunlin, 2024-04-11:
the pins that are routed to the encoder 5 pin connector should be broken out to 1' pitched through hole for non-motorGo usage

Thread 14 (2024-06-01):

Design review - improvements (WIP)

dan-gies, 2024-06-01:
Commit: 740275f0238d911437
Issue severity:
* 🔴critical
* 🟡should-fix

Hi! As discussed, I took a pass at reviewing V1.3 of this board.

# Schematic
## Power
🔴 These capacitors aren't connected to GND. As it is, they aren't doing anything for you. I'm surprised the buck is working at all. I have a feeling that if you put the output on an oscilloscope, it's a mess, barely regulating properly. A few days ago, I tested a buck circuit for someone that has missing/improperly configured capacitors. The excessive ringing on the input rail killed the part. The nefarious thing is that if you're probing with a DMM, the **average** voltage looks fine, but the high voltage spikes could easily kill stuff downstream.

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

From another design, input ringing because capacitors weren't present:

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

🔴 The 5V output of the buck reg. is directly connected to VBUS from the USB-C connector. This is **bad** - if both the battery and VBUS get connected, there's **contention** they're fighting to drive the rail. Whichever voltage supply is ever so slightly higher than the other will be back-feeding reverse current in the other supply - very bad.

The right way to do this is with a **power-OR** (AKA "power-mux") circuit. The easiest way to do this is with two diodes to "share" the load - this way, you can't back-feed one supply with the other. You can also get power-mux/power-OR IC's do to this more efficiently, with "ideal diode" circuits (MOSFET drivers which sense voltage drop and behave like a very low loss diode).

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

# Layout
## Via-in-pad
Generally, via in pad shouldn't be used unless you're plugging+plating the vias (often referred to as "plug+plate", "fill+cap"). Otherwise, solder wicks down the holes and away from the pads.

Plug-and-plate:
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

Via-in-pad **without** plugging+plating, solder wicks off of pad and down hole, resulting in disconnected component:
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

Unless you really need via-in-pad, don't do it. The one place it's generally OK to do via-in-pad **without** plug+plate is on thermal pads of components like QFNs. Plug+plate is better (better thermal performance, less chance of solder defect), but I've gotten away tons of times with the classic "windowed solder paste" technique, where there's enough solder paste away from the via that it doesn't wick off the pad, and the pad is huge. A good CM will X-ray to confirm that solder hasn't wicked off of pads.

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

---

🟡 In your design, you've used via-in-pad often. I'd reconsider this and move the via off-pad to improve manufacturing yield.

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

On your thermal pad of the motor drivers, the solder paste is right over the vias. Instead, I'd make the vias smaller (0.2mm if you can, or 0.25mm) and put a single paste opening nestled between the vias.

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

## Thermal pads
🟡 Thermal pads are essential to transfer heat away from components. You're doing yourself a disservice by having thermal reliefs on the inner layers. I'd make these direct-connects to the vias under the part.

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

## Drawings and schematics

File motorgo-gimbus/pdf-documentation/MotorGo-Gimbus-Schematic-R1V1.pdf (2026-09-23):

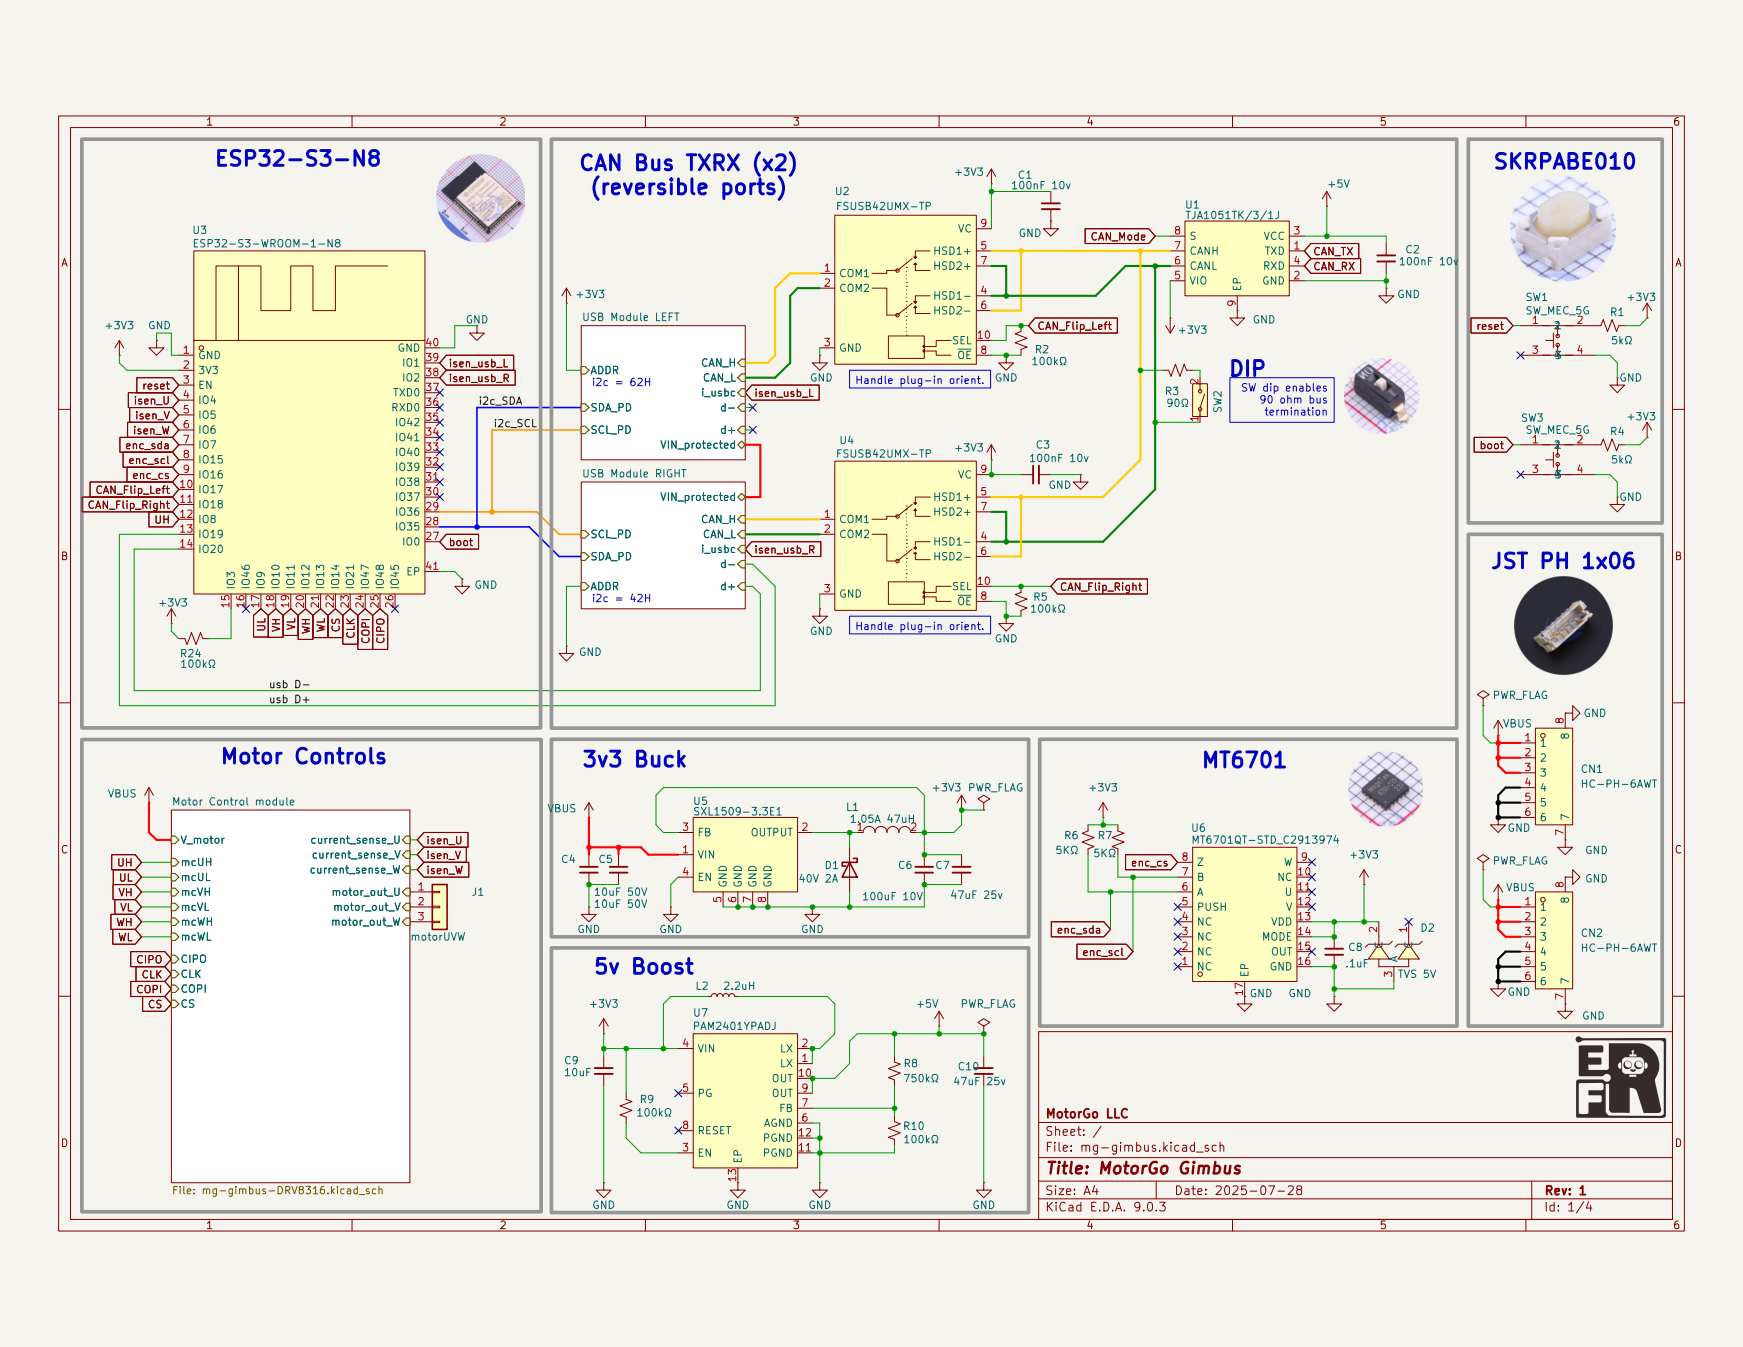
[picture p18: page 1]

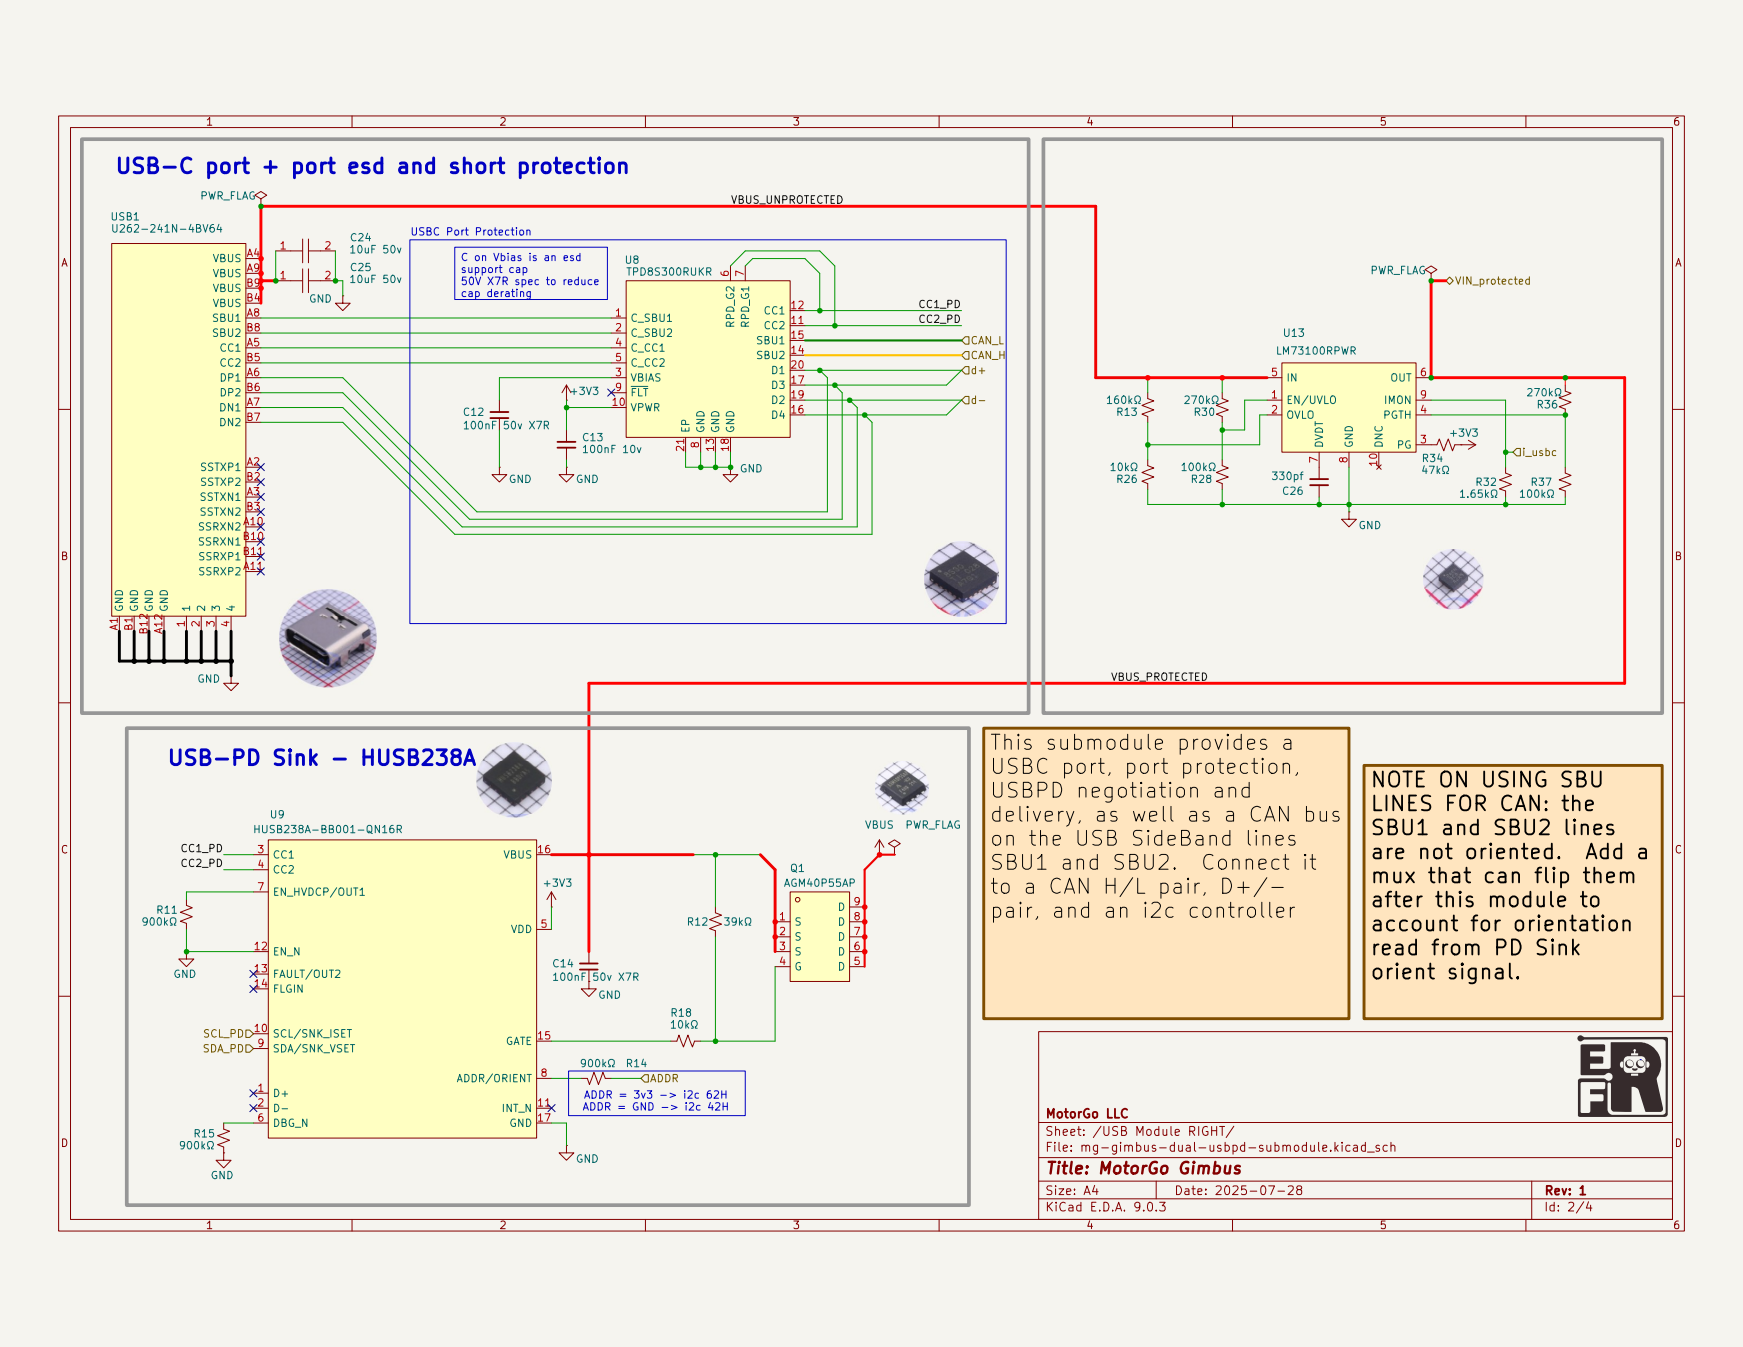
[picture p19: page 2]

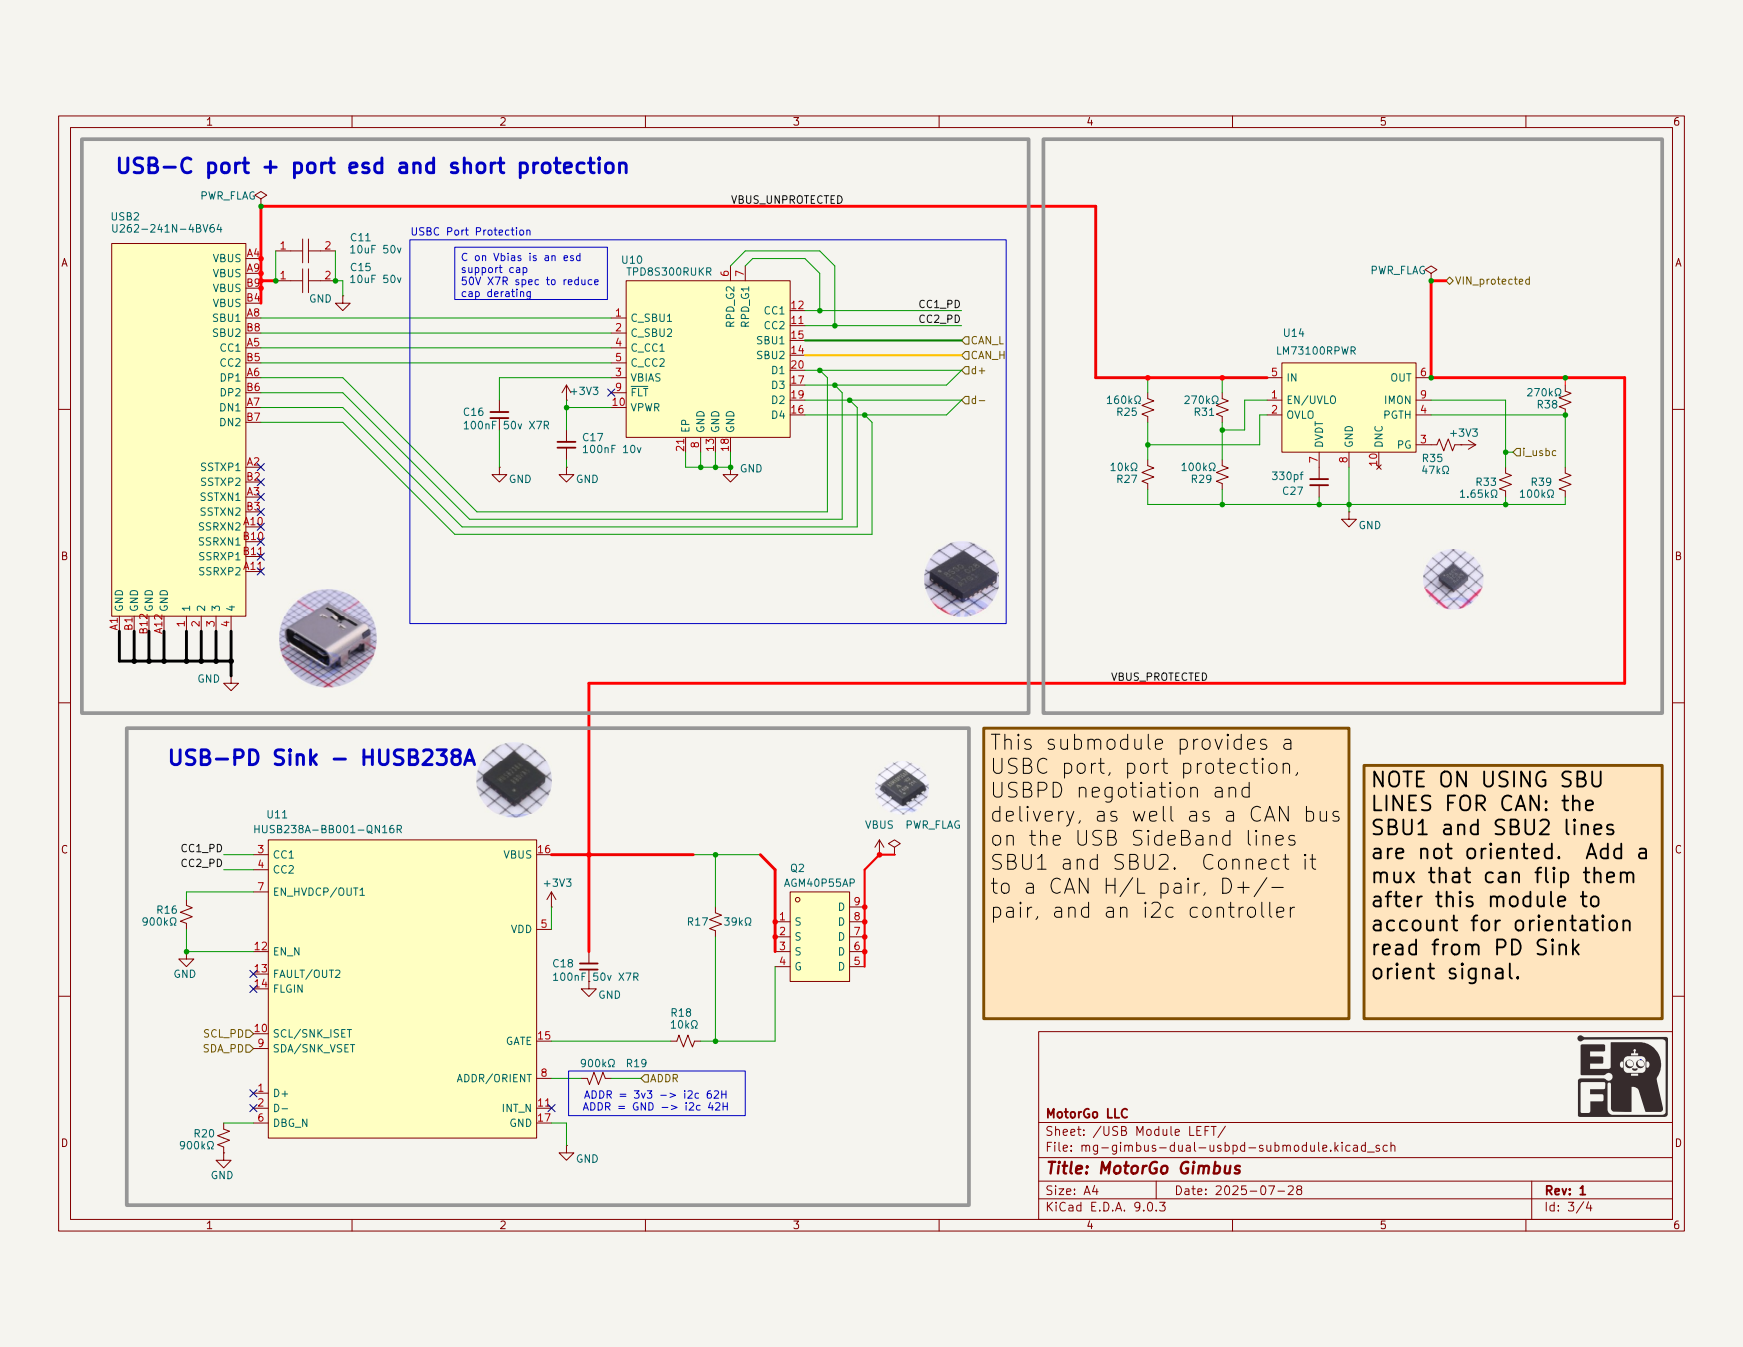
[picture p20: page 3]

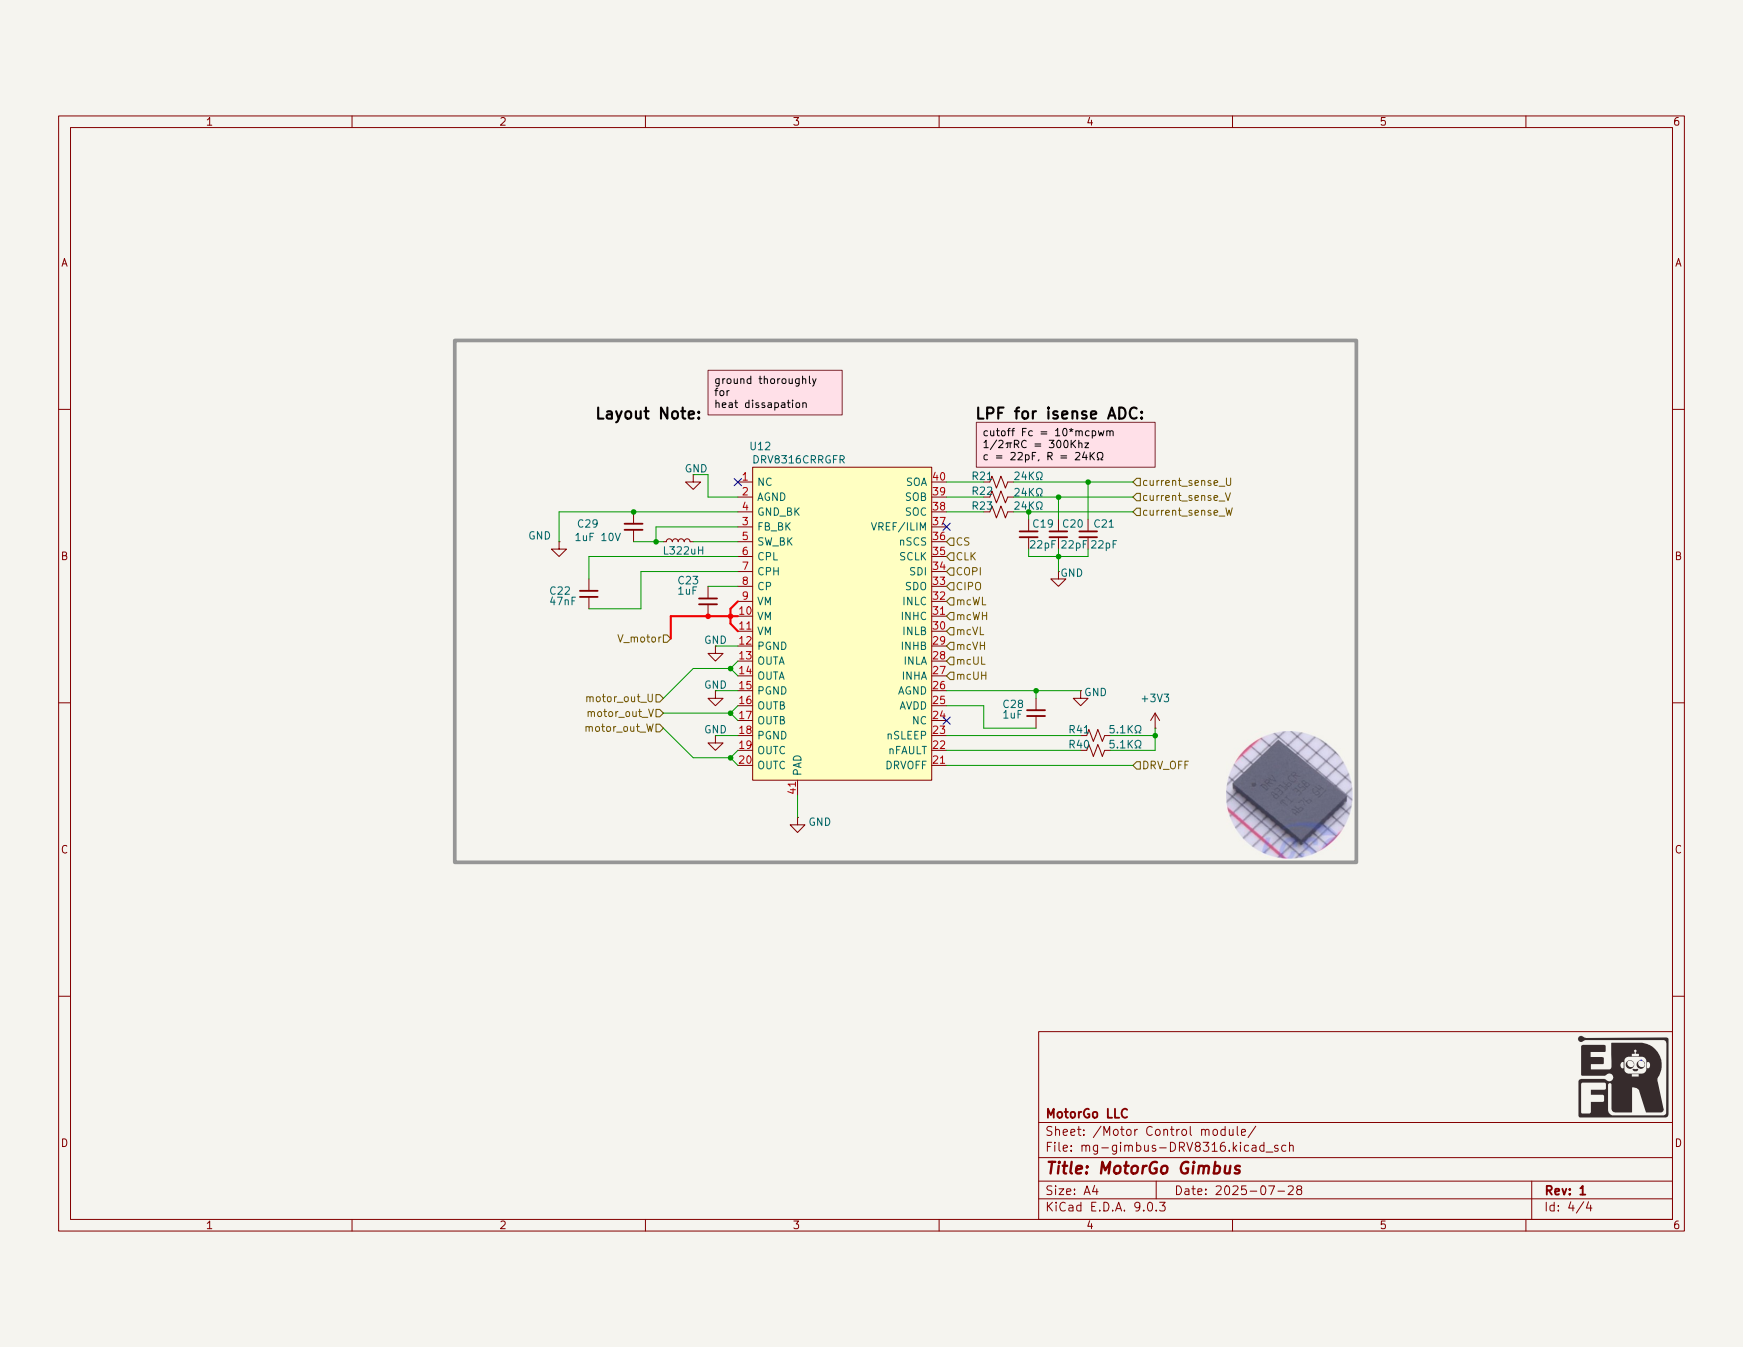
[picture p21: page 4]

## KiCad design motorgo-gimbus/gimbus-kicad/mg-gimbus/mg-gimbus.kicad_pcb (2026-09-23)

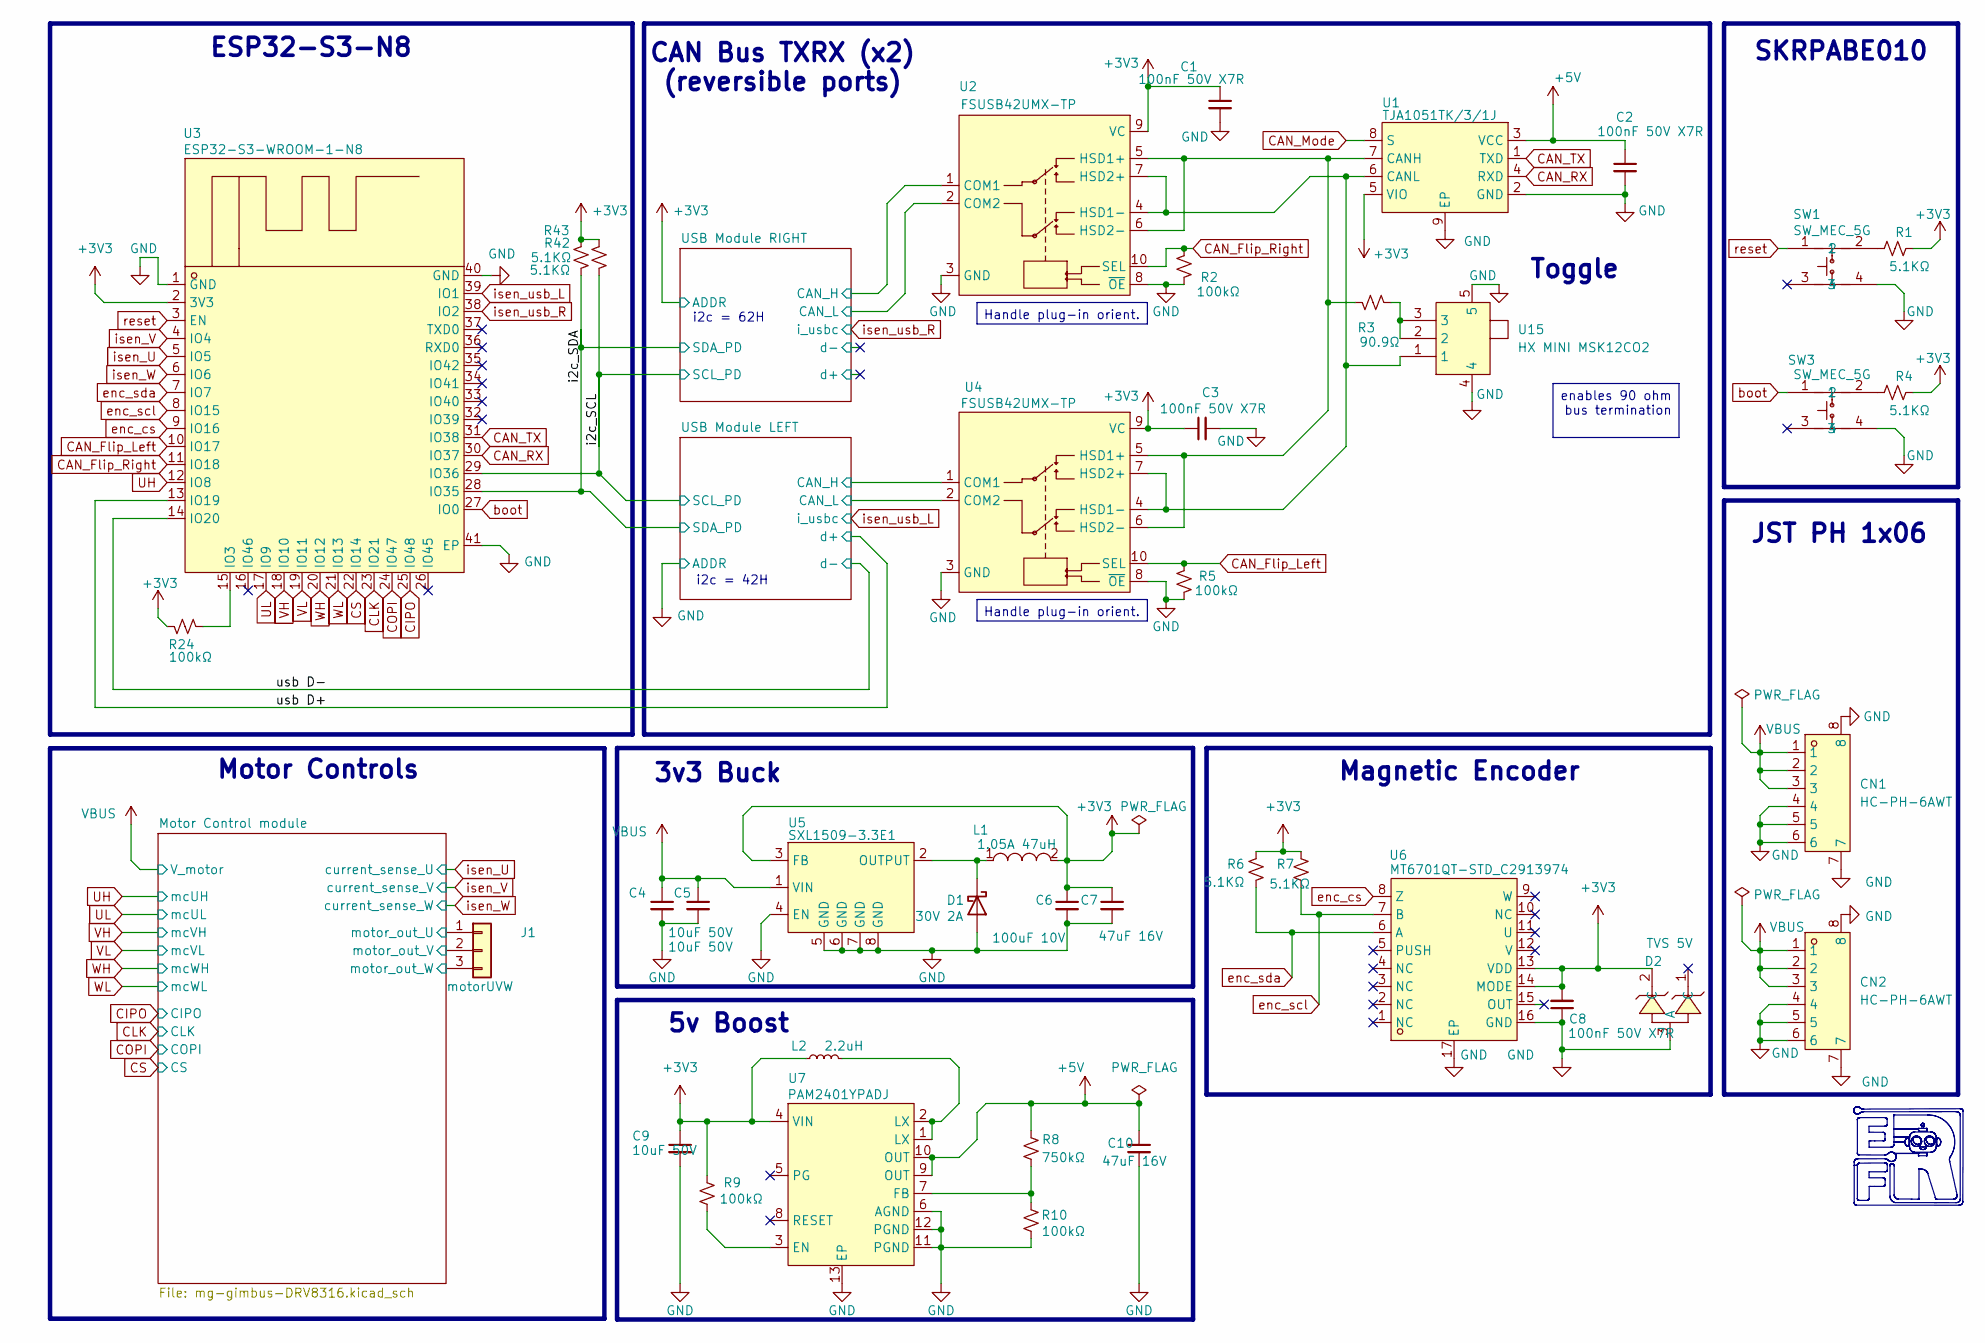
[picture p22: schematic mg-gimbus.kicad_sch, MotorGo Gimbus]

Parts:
C1, C2, C3, C8: 100nF 50V X7R; C_0402_1005Metric; LCSC Part C152814
C4, C5, C9: 10uF 50V; C_1206_3216Metric; LCSC Part C13585
C6: 100uF 10V; CAP-SMD_L7.3-W4.3_SA11CM470A19R55XXX; LCSC Part C42400366
C7, C10: 47uF 16V; C_1206_3216Metric; LCSC Part C172351
CN1, CN2: HC-PH-6AWT; CONN-SMD_6P-P2.00_HCTL_HC-PH-6AWT; LCSC Part C2845446
D1: 30V 2A; D_0603_1608Metric; LCSC Part C35621074
D2: TVS 5V; SOT-723_L1.2-W0.8-P0.40-LS1.2-BR; LCSC Part C896625
J1: motorUVW; Gimbus_Motor; LCSC Part n/a
L1: 1.05A 47uH; IND-SMD_L7.2-W6.6_GPSR07X0; LCSC Part C2929441
L2: 2.2uH; L_1008_2520Metric; LCSC Part C86092
R1, R4, R6, R7, R42, R43: 5.1KΩ; R_0402_1005Metric; LCSC Part C25905
R2, R5, R9, R10, R24: 100kΩ; R_0402_1005Metric; LCSC Part C25741
R3: 90.9Ω; R_0402_1005Metric; LCSC Part C208954
R8: 750kΩ; R_0402_1005Metric; LCSC Part C43291
SW1, SW3: SW_MEC_5G; KEY-SMD_4P-L4.2-W3.2-P2.20-LS4.6; LCSC Part C115360
U1: TJA1051TK/3/1J; HVSON-8_L3.0-W3.0-P0.65-BL-EP; LCSC Part C2875699
U2, U4: FSUSB42UMX-TP; XQFN-10_L1.8-W1.4-P0.40-TL; LCSC Part C42370490
U3: ESP32-S3-WROOM-1-N8; WIFIM-SMD_ESP32-S3-WROOM-1-N8; LCSC Part C2913198
U5: SXL1509-3.3E1; SOP-8_L4.9-W3.9-P1.27-LS6.0-BL-1; LCSC Part C33960106
U6: MT6701QT-STD_C2913974; QFN-16_L3.0-W3.0-P0.50-TL-EP1.7; LCSC Part C2913974
U7: PAM2401YPADJ; WDFN-12_L3.0-W3.0-P0.45-BL-EP; LCSC Part C490380
U15: HX MINI MSK12CO2; SW-SMD_MSK12CO2; LCSC Part C5149840

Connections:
+3V3: C1.1, C3.1, C6.1, C7.1, C8.2, C9.1, D2.2 (C), L1.2, L2.1, R1.2, R4.2, R6.1, R7.1, R9.2, R24.2, R42.1, R43.1, U1.5 (VIO), U2.9 (VC), U3.2 (3V3), U4.9 (VC), U5.3 (FB), U6.13 (VDD), U6.14 (MODE), U7.4 (VIN); also elsewhere on the board
+5V: C2.1, C10.1, R8.2, U1.3 (VCC), U7.9 (OUT), U7.10 (OUT)
/Motor Control module/motor_out_U: J1.1; also elsewhere on the board
/Motor Control module/motor_out_V: J1.2; also elsewhere on the board
/Motor Control module/motor_out_W: J1.3; also elsewhere on the board
/USB Module LEFT/CAN_H: U4.1 (COM1); also elsewhere on the board
/USB Module LEFT/CAN_L: U4.2 (COM2); also elsewhere on the board
/USB Module RIGHT/CAN_H: U2.1 (COM1); also elsewhere on the board
/USB Module RIGHT/CAN_L: U2.2 (COM2); also elsewhere on the board
/i2c_SCL: R42.2, U3.29 (IO36); also elsewhere on the board
/i2c_SDA: R43.2, U3.28 (IO35); also elsewhere on the board
/usb D+: U3.13 (IO19); also elsewhere on the board
/usb D-: U3.14 (IO20); also elsewhere on the board
CAN_Flip_Left: R5.2, U3.10 (IO17), U4.10 (SEL)
CAN_Flip_Right: R2.2, U2.10 (SEL), U3.11 (IO18)
CAN_Mode: U1.8 (S)
CAN_RX: U1.4 (RXD), U3.30 (IO37)
CAN_TX: U1.1 (TXD), U3.31 (IO38)
CIPO: U3.25 (IO48); also elsewhere on the board
CLK: U3.23 (IO21); also elsewhere on the board
COPI: U3.24 (IO47); also elsewhere on the board
CS: U3.22 (IO14); also elsewhere on the board
GND: C1.2, C2.2, C3.2, C4.2, C5.2, C6.2, C7.2, C8.1, C9.2, C10.2, CN1.4, CN1.5, CN1.6, CN1.7, CN1.8, CN2.4, CN2.5, CN2.6, CN2.7, CN2.8, D1.2 (A), D2.3 (A), R2.1, R5.1, R10.1, SW1.4, SW3.4, U1.2 (GND), U1.9 (EP), U2.3 (GND), U2.8 (~OE), U3.1 (GND), U3.40 (GND), U3.41 (EP), U4.3 (GND), U4.8 (~OE), U5.4 (EN), U5.5 (GND), U5.6 (GND), U5.7 (GND), U5.8 (GND), U6.16 (GND), U6.17 (EP), U7.6 (AGND), U7.11 (PGND), U7.12 (PGND), U7.13 (EP), U15.4, U15.5; also elsewhere on the board
unnamed: D1.1 (K), L1.1, U5.2 (OUTPUT)
unnamed: L2.2, U7.1 (LX), U7.2 (LX)
unnamed: R1.1, SW1.2
unnamed: R3.2, U15.2, U15.3
unnamed: R4.1, SW3.2
unnamed: R3.1, U1.7 (CANH), U2.5 (HSD1+), U2.6 (HSD2-), U4.5 (HSD1+), U4.6 (HSD2-)
unnamed: U1.6 (CANL), U2.4 (HSD1-), U2.7 (HSD2+), U4.4 (HSD1-), U4.7 (HSD2+), U15.1
unnamed: R24.1, U3.15 (IO3)
unnamed: R9.1, U7.3 (EN)
unnamed: R8.1, R10.2, U7.7 (FB)
UH: U3.12 (IO8); also elsewhere on the board
UL: U3.17 (IO9); also elsewhere on the board
VBUS: C4.1, C5.1, CN1.1, CN1.2, CN1.3, CN2.1, CN2.2, CN2.3, U5.1 (VIN); also elsewhere on the board
VH: U3.18 (IO10); also elsewhere on the board
VL: U3.19 (IO11); also elsewhere on the board
WH: U3.20 (IO12); also elsewhere on the board
WL: U3.21 (IO13); also elsewhere on the board
boot: SW3.1, U3.27 (IO0)
enc_cs: U3.9 (IO16), U6.8 (Z)
enc_scl: R7.2, U3.8 (IO15), U6.7 (B)
enc_sda: R6.2, U3.7 (IO7), U6.6 (A)
isen_U: U3.5 (IO5); also elsewhere on the board
isen_V: U3.4 (IO4); also elsewhere on the board
isen_W: U3.6 (IO6); also elsewhere on the board
isen_usb_L: U3.39 (IO1); also elsewhere on the board
isen_usb_R: U3.38 (IO2); also elsewhere on the board
reset: SW1.1, U3.3 (EN)

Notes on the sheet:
i2c = 62H
ESP32-S3-N8
i2c = 42H
Toggle
JST PH 1x06
Magnetic Encoder
5v Boost
SKRPABE010
CAN Bus TXRX (x2) (reversible ports)
3v3 Buck
Motor Controls
Handle plug-in orient.
enables 90 ohm bus termination

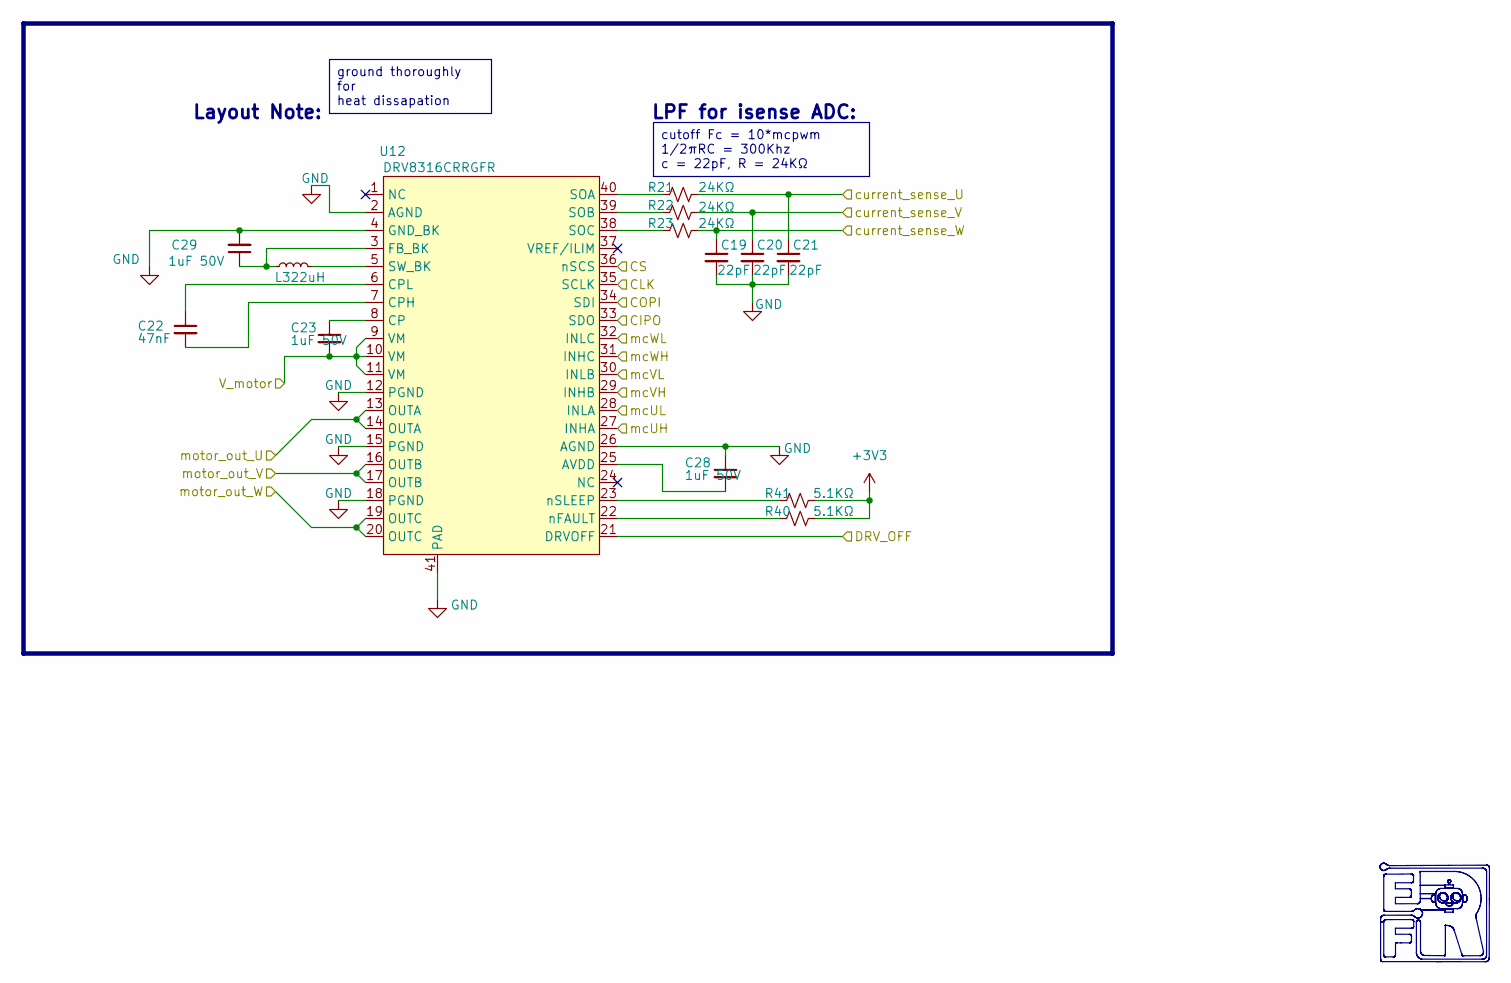
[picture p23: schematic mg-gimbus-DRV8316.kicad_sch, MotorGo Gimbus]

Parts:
C19, C20, C21: 22pF; C_0402_1005Metric; LCSC Part C76960
C22: 47nF; C_0402_1005Metric; LCSC Part C82219
C23, C28, C29: 1uF 50V; C_0805_2012Metric; LCSC Part C28323
L3: 22uH; L_0603_1608Metric; LCSC Part C383393
R21, R22, R23: 24KΩ; R_0402_1005Metric; LCSC Part C25769
R40, R41: 5.1KΩ; R_0402_1005Metric; LCSC Part C25905
U12: DRV8316CRRGFR; VQFN-40_L7.0-W5.0-P0.50-BL-EP5.7; LCSC Part C5447274

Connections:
+3V3: R40.2, R41.2; also elsewhere on the board
/Motor Control module/DRV_OFF: U12.21 (DRVOFF)
/Motor Control module/motor_out_U: U12.13 (OUTA), U12.14 (OUTA); also elsewhere on the board
/Motor Control module/motor_out_V: U12.16 (OUTB), U12.17 (OUTB); also elsewhere on the board
/Motor Control module/motor_out_W: U12.19 (OUTC), U12.20 (OUTC); also elsewhere on the board
CIPO: U12.33 (SDO); also elsewhere on the board
CLK: U12.35 (SCLK); also elsewhere on the board
COPI: U12.34 (SDI); also elsewhere on the board
CS: U12.36 (nSCS); also elsewhere on the board
GND: C19.2, C20.2, C21.2, C28.1, C29.2, U12.2 (AGND), U12.4 (GND_BK), U12.12 (PGND), U12.15 (PGND), U12.18 (PGND), U12.26 (AGND), U12.41 (PAD); also elsewhere on the board
unnamed: C28.2, U12.25 (AVDD)
unnamed: C23.1, U12.8 (CP)
unnamed: C22.2, U12.7 (CPH)
unnamed: C22.1, U12.6 (CPL)
unnamed: C29.1, L3.1, U12.3 (FB_BK)
unnamed: R21.1, U12.40 (SOA)
unnamed: R22.1, U12.39 (SOB)
unnamed: R23.1, U12.38 (SOC)
unnamed: L3.2, U12.5 (SW_BK)
unnamed: R40.1, U12.22 (nFAULT)
unnamed: R41.1, U12.23 (nSLEEP)
UH: U12.27 (INHA); also elsewhere on the board
UL: U12.28 (INLA); also elsewhere on the board
VBUS: C23.2, U12.9 (VM), U12.10 (VM), U12.11 (VM); also elsewhere on the board
VH: U12.29 (INHB); also elsewhere on the board
VL: U12.30 (INLB); also elsewhere on the board
WH: U12.31 (INHC); also elsewhere on the board
WL: U12.32 (INLC); also elsewhere on the board
isen_U: C21.1, R21.2; also elsewhere on the board
isen_V: C20.1, R22.2; also elsewhere on the board
isen_W: C19.1, R23.2; also elsewhere on the board

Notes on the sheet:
Layout Note:
LPF for isense ADC:
cutoff Fc = 10*mcpwm 1/2πRC = 300Khz c = 22pF, R = 24KΩ
ground thoroughly for heat dissapation

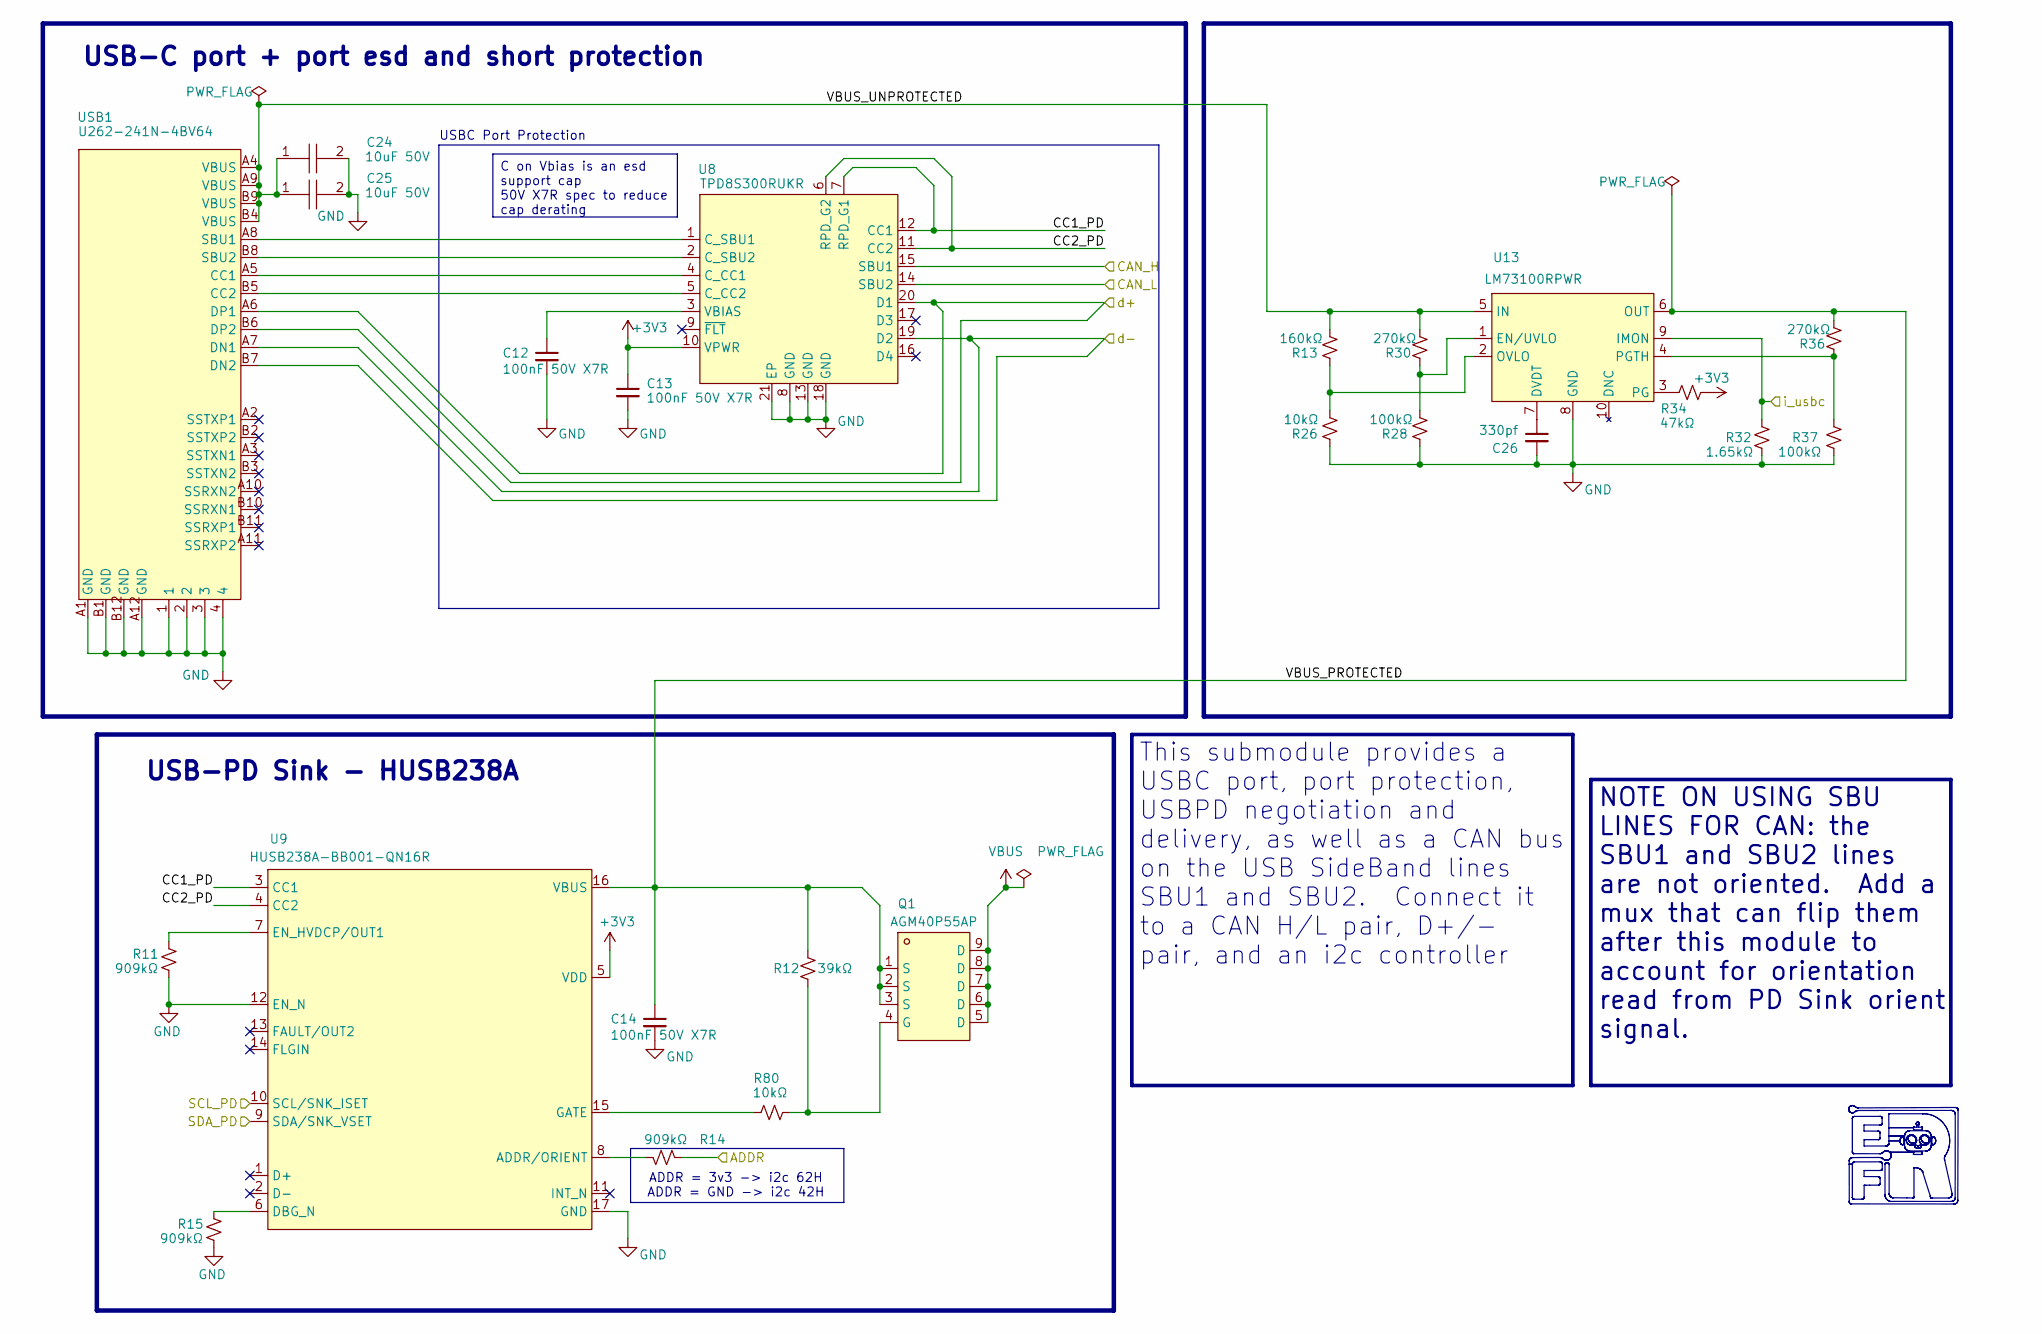
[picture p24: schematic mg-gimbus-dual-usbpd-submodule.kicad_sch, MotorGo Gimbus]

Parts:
C12, C13, C14: 100nF 50V X7R; C_0402_1005Metric; LCSC Part C152814
C24, C25: 10uF 50V; C_1206_3216Metric; LCSC Part C13585
C26: 330pf; C_0402_1005Metric; LCSC Part C13533
Q1: AGM40P55AP; DFN-8_L3.3-W3.3-P0.65-BL-3; LCSC Part C5340112
R11, R14, R15: 909kΩ; R_0402_1005Metric; LCSC Part C25799
R12: 39kΩ; R_0402_1005Metric; LCSC Part C25783
R13: 160kΩ; R_0402_1005Metric; LCSC Part C25757
R26, R80: 10kΩ; R_0402_1005Metric; LCSC Part C25744
R28, R37: 100kΩ; R_0402_1005Metric; LCSC Part C25741
R30, R36: 270kΩ; R_0402_1005Metric; LCSC Part C25770
R32: 1.65kΩ; R_0402_1005Metric; LCSC Part C25869
R34: 47kΩ; R_0402_1005Metric; LCSC Part C25792
U8: TPD8S300RUKR; WQFN-20_L3.0-W3.0-P0.40-TL-EP; LCSC Part C571205
U9: HUSB238A-BB001-QN16R; QFN-16_L3.0-W3.0-P0.50-BL-EP1.7; LCSC Part C24833806
U13: LM73100RPWR; VQFN-10_L2.0-W2.0-P0.45-TL; LCSC Part C3210761
USB1: U262-241N-4BV64; USB-C-SMD_TYC-324G; LCSC Part C388660

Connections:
+3V3: C13.1, R14.2, R34.1, U8.10 (VPWR), U9.5 (VDD); also elsewhere on the board
/USB Module RIGHT/CAN_H: U8.15 (SBU1); also elsewhere on the board
/USB Module RIGHT/CAN_L: U8.14 (SBU2); also elsewhere on the board
/USB Module RIGHT/CC1_PD: U8.7 (RPD_G1), U8.12 (CC1), U9.3 (CC1)
/USB Module RIGHT/CC2_PD: U8.6 (RPD_G2), U8.11 (CC2), U9.4 (CC2)
/USB Module RIGHT/VBUS_PROTECTED: C14.1, Q1.1 (S), Q1.2 (S), Q1.3 (S), R12.2, R36.2, U9.16 (VBUS), U13.6 (OUT)
/USB Module RIGHT/VBUS_UNPROTECTED: C24.1, C25.1, R13.2, R30.2, U13.5 (IN), USB1.A4 (VBUS), USB1.A9 (VBUS), USB1.B4 (VBUS), USB1.B9 (VBUS)
/USB Module RIGHT/d+: U8.20 (D1), USB1.A6 (DP1), USB1.B6 (DP2)
/USB Module RIGHT/d-: U8.19 (D2), USB1.A7 (DN1), USB1.B7 (DN2)
/i2c_SCL: U9.10 (SCL/SNK_ISET); also elsewhere on the board
/i2c_SDA: U9.9 (SDA/SNK_VSET); also elsewhere on the board
GND: C12.2, C13.2, C14.2, C24.2, C25.2, C26.2, R11.1, R15.1, R26.1, R28.1, R32.1, R37.1, U8.8 (GND), U8.13 (GND), U8.18 (GND), U8.21 (EP), U9.12 (EN_N), U9.17 (GND), U13.8 (GND), USB1.1, USB1.2, USB1.3, USB1.4, USB1.A1 (GND), USB1.A12 (GND), USB1.B1 (GND), USB1.B12 (GND); also elsewhere on the board
unnamed: Q1.4 (G), R12.1, R80.2
unnamed: U8.4 (C_CC1), USB1.A5 (CC1)
unnamed: U8.5 (C_CC2), USB1.B5 (CC2)
unnamed: U8.1 (C_SBU1), USB1.A8 (SBU1)
unnamed: U8.2 (C_SBU2), USB1.B8 (SBU2)
unnamed: C12.1, U8.3 (VBIAS)
unnamed: R14.1, U9.8 (ADDR/ORIENT)
unnamed: R15.2, U9.6 (DBG_N)
unnamed: R11.2, U9.7 (EN_HVDCP/OUT1)
unnamed: R80.1, U9.15 (GATE)
unnamed: C26.1, U13.7 (DVDT)
unnamed: R28.2, R30.1, U13.1 (EN/UVLO)
unnamed: R13.1, R26.2, U13.2 (OVLO)
unnamed: R34.2, U13.3 (PG)
unnamed: R36.1, R37.2, U13.4 (PGTH)
VBUS: Q1.5 (D), Q1.6 (D), Q1.7 (D), Q1.8 (D), Q1.9 (D); also elsewhere on the board
isen_usb_R: R32.2, U13.9 (IMON); also elsewhere on the board

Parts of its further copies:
C11, C15: 10uF 50V; C_1206_3216Metric; LCSC Part C13585
C16, C17, C18: 100nF 50V X7R; C_0402_1005Metric; LCSC Part C152814
C27: 330pf; C_0402_1005Metric; LCSC Part C13533
Q2: AGM40P55AP; DFN-8_L3.3-W3.3-P0.65-BL-3; LCSC Part C5340112
R16, R19, R20: 909kΩ; R_0402_1005Metric; LCSC Part C25799
R17: 39kΩ; R_0402_1005Metric; LCSC Part C25783
R18, R27: 10kΩ; R_0402_1005Metric; LCSC Part C25744
R25: 160kΩ; R_0402_1005Metric; LCSC Part C25757
R29, R39: 100kΩ; R_0402_1005Metric; LCSC Part C25741
R31, R38: 270kΩ; R_0402_1005Metric; LCSC Part C25770
R33: 1.65kΩ; R_0402_1005Metric; LCSC Part C25869
R35: 47kΩ; R_0402_1005Metric; LCSC Part C25792
U10: TPD8S300RUKR; WQFN-20_L3.0-W3.0-P0.40-TL-EP; LCSC Part C571205
U11: HUSB238A-BB001-QN16R; QFN-16_L3.0-W3.0-P0.50-BL-EP1.7; LCSC Part C24833806
U14: LM73100RPWR; VQFN-10_L2.0-W2.0-P0.45-TL; LCSC Part C3210761
USB2: U262-241N-4BV64; USB-C-SMD_TYC-324G; LCSC Part C388660

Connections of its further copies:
+3V3: C17.1, R35.1, U10.10 (VPWR), U11.5 (VDD); also elsewhere on the board
/USB Module LEFT/CAN_H: U10.15 (SBU1); also elsewhere on the board
/USB Module LEFT/CAN_L: U10.14 (SBU2); also elsewhere on the board
/USB Module LEFT/CC1_PD: U10.7 (RPD_G1), U10.12 (CC1), U11.3 (CC1)
/USB Module LEFT/CC2_PD: U10.6 (RPD_G2), U10.11 (CC2), U11.4 (CC2)
/USB Module LEFT/VBUS_PROTECTED: C18.1, Q2.1 (S), Q2.2 (S), Q2.3 (S), R17.2, R38.2, U11.16 (VBUS), U14.6 (OUT)
/USB Module LEFT/VBUS_UNPROTECTED: C11.1, C15.1, R25.2, R31.2, U14.5 (IN), USB2.A4 (VBUS), USB2.A9 (VBUS), USB2.B4 (VBUS), USB2.B9 (VBUS)
/i2c_SCL: U11.10 (SCL/SNK_ISET); also elsewhere on the board
/i2c_SDA: U11.9 (SDA/SNK_VSET); also elsewhere on the board
/usb D+: U10.20 (D1), USB2.A6 (DP1), USB2.B6 (DP2); also elsewhere on the board
/usb D-: U10.19 (D2), USB2.A7 (DN1), USB2.B7 (DN2); also elsewhere on the board
GND: C11.2, C15.2, C16.2, C17.2, C18.2, C27.2, R16.1, R19.2, R20.1, R27.1, R29.1, R33.1, R39.1, U10.8 (GND), U10.13 (GND), U10.18 (GND), U10.21 (EP), U11.12 (EN_N), U11.17 (GND), U14.8 (GND), USB2.1, USB2.2, USB2.3, USB2.4, USB2.A1 (GND), USB2.A12 (GND), USB2.B1 (GND), USB2.B12 (GND); also elsewhere on the board
unnamed: Q2.4 (G), R17.1, R18.2
unnamed: U10.4 (C_CC1), USB2.A5 (CC1)
unnamed: U10.5 (C_CC2), USB2.B5 (CC2)
unnamed: U10.1 (C_SBU1), USB2.A8 (SBU1)
unnamed: U10.2 (C_SBU2), USB2.B8 (SBU2)
unnamed: C16.1, U10.3 (VBIAS)
unnamed: R19.1, U11.8 (ADDR/ORIENT)
unnamed: R20.2, U11.6 (DBG_N)
unnamed: R16.2, U11.7 (EN_HVDCP/OUT1)
unnamed: R18.1, U11.15 (GATE)
unnamed: C27.1, U14.7 (DVDT)
unnamed: R29.2, R31.1, U14.1 (EN/UVLO)
unnamed: R25.1, R27.2, U14.2 (OVLO)
unnamed: R35.2, U14.3 (PG)
unnamed: R38.1, R39.2, U14.4 (PGTH)
VBUS: Q2.5 (D), Q2.6 (D), Q2.7 (D), Q2.8 (D), Q2.9 (D); also elsewhere on the board
isen_usb_L: R33.2, U14.9 (IMON); also elsewhere on the board

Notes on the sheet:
ADDR = 3v3 -> i2c 62H ADDR = GND -> i2c 42H
USB-C port + port esd and short protection
USBC Port Protection
USB-PD Sink - HUSB238A
C on Vbias is an esd support cap 50V X7R spec to reduce cap derating
NOTE ON USING SBU LINES FOR CAN: the SBU1 and SBU2 lines are not oriented. Add a mux that can flip them after this module to account for orientation read from PD Sink orient signal.
This submodule provides a USBC port, port protection, USBPD negotiation and delivery, as well as a CAN bus on the USB SideBand lines SBU1 and SBU2. Connect it to a CAN H/L pair, D+/- pair, and an i2c controller

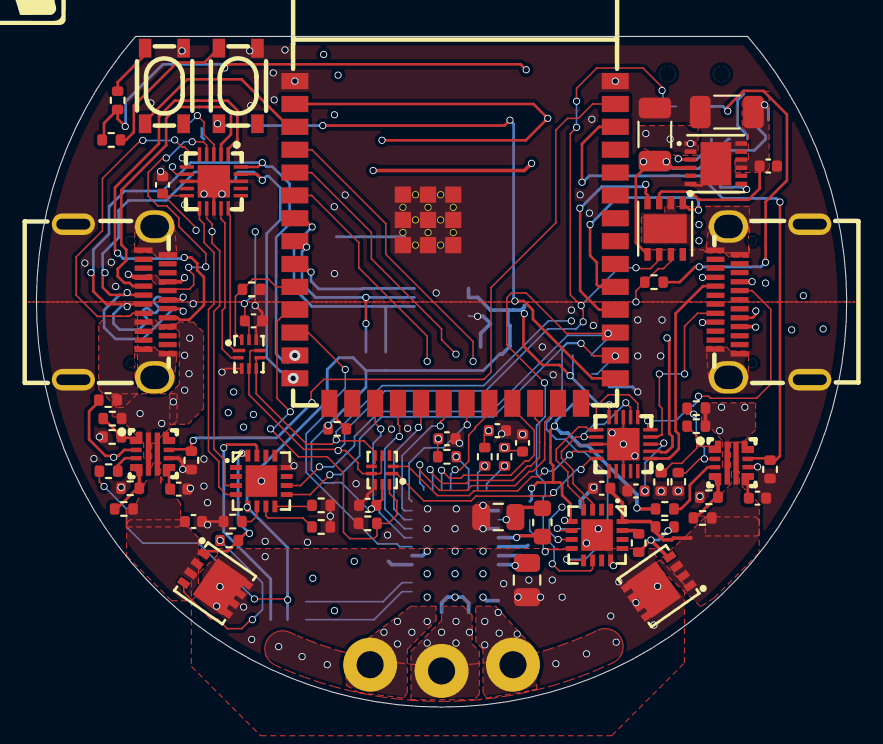
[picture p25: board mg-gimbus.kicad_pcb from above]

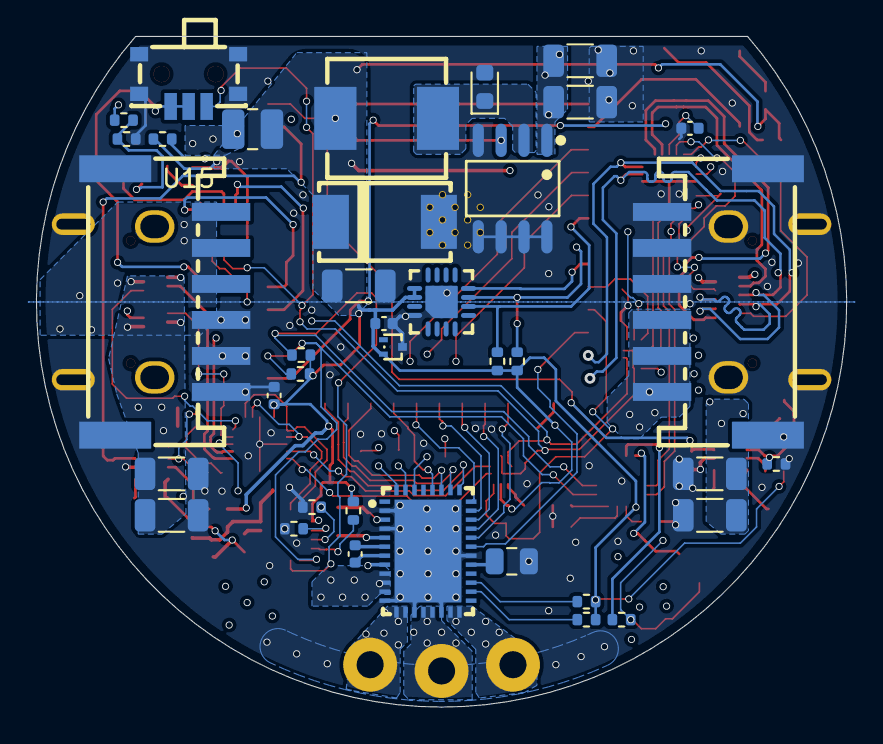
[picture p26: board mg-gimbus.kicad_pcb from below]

Board: 4 copper layers, 45.0 x 37.3 mm, 102 parts (38 on the bottom side), 100 nets.

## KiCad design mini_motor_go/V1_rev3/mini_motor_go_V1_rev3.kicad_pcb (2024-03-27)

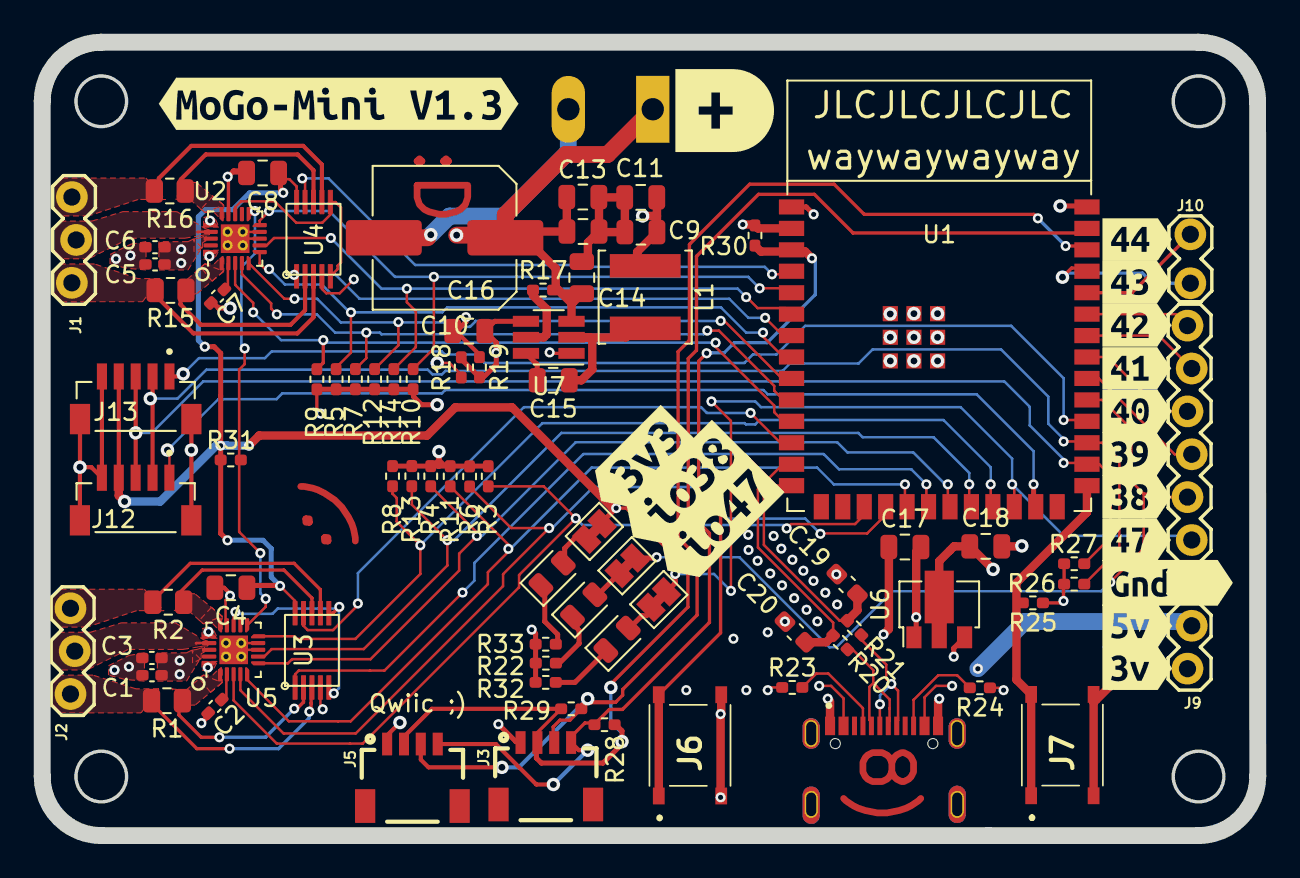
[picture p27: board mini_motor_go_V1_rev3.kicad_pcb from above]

Board: 4 copper layers, 72.0 x 47.0 mm, 95 parts (0 on the bottom side), 68 nets.

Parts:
C1, C2, C3, C5, C6, C7: 10NF; C_0402_1005Metric_Pad0.74x0.62mm_HandSolder
C4, C8: 0.1UF; C_0805_2012Metric
C9, C11, C18: 22uF; C_0805_2012Metric
C10: 220uF; C_Elec_8x10.2
C12, C13, C17: 10uF; C_0805_2012Metric
C14, C15, C16: .1uF; C_0805_2012Metric
C19, C20: DNP; C_0603_1608Metric_Pad1.08x0.95mm_HandSolder
D1, D2, D3: LED; LED_0805_2012Metric
J1, J2: CONN_03POLAR_LOCK; 1X03_LOCK
J3, J5: I2C_STANDARDQWIIC; 1X04_1MM_RA
J6, J7: PTS526SM08SMTR2LFS
J8: TerminalBlock_Altech_AK300-2_P5.00mm
J9: Conn_01x09_Pin; 1X09_LOCK
J10: Conn_01x02_Pin; 1X02_LOCK
J11: USB4520-03-0-A_REVA; GCT_USB4520-03-0-A_REVA
J12, J13: BM05B-SRSS-TB_LF__SN_; JST_BM05B-SRSS-TB_LF__SN_
JP1, JP2, JP3: SolderJumper_2_Bridged; SolderJumper-2_P1.3mm_Bridged_Pad1.0x1.5mm
L1: SRP3212A-4R7M; L_Changjiang_FNR5020S
R1, R2, R15, R16: R_Shunt_US; R_0805_2012Metric
R3, R4, R5, R6, R7, R8, R9, R10, R11, R12, R13, R14: 1K; R_0402_1005Metric_Pad0.72x0.64mm_HandSolder
R17, R19: 54.9k; R_0402_1005Metric_Pad0.72x0.64mm_HandSolder
R18: 10k; R_0402_1005Metric_Pad0.72x0.64mm_HandSolder
R20, R21: 0; R_0402_1005Metric_Pad0.72x0.64mm_HandSolder
R22, R32, R33: 1k; R_0402_1005Metric_Pad0.72x0.64mm_HandSolder
R23, R24, R25, R26, R27, R28, R29, R30, R31: 5k1; R_0402_1005Metric_Pad0.72x0.64mm_HandSolder
U1: ESP32-S3-WROOM-1
U2, U5: TMC6300; TMC6300 3x3mm
U3, U4: INA2181; INA2181_VSSOP_10
U6: AZ1117C; SOT-89-3
U7: TPS562208; SOT-23-6_Handsoldering
kibuzzard-65733A0D: G***; kibuzzard-65733A0D
kibuzzard-65733A1B: G***; kibuzzard-65733A1B
kibuzzard-65733C02: G***; kibuzzard-65733C02
kibuzzard-65733C2B: G***; kibuzzard-65733C2B
kibuzzard-65733C3A: G***; kibuzzard-65733C3A
kibuzzard-65733C12: G***; kibuzzard-65733C12
kibuzzard-65733C20: G***; kibuzzard-65733C20
kibuzzard-65733C45: G***; kibuzzard-65733C45
kibuzzard-65733C60: G***; kibuzzard-65733C60
kibuzzard-65733C66: G***; kibuzzard-65733C66
kibuzzard-65733C85: G***; kibuzzard-65733C85
kibuzzard-65733FCF: G***; kibuzzard-65733FCF
kibuzzard-65733FF1: G***; kibuzzard-65733FF1
kibuzzard-66038D2F: G***; kibuzzard-66038D2F
kibuzzard-6573395A: G***; kibuzzard-6573395A
kibuzzard-65733965: G***; kibuzzard-65733965

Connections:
+3.3V: C4.1, C8.1, C18.1, J3.2 (VCC), J5.2 (VCC), J9.1, J12.4, J13.4, JP3.2 (B), R25.1, R26.1, R27.1, R28.1, R29.1, R30.1, R31.1, U1.2 (3V3), U3.10 (VS), U4.10 (VS), U6.2 (out)
+5V: C9.1, C11.1, C16.1, C17.1, J9.2, J11.A4_B9 (VBUS_A), J11.B4_A9 (VBUS_B), L1.1, R19.1, U6.3 (in)
+BATT: C1.1, C2.2, C3.2, C5.1, C6.2, C7.2, C10.1 (+), C12.2, C13.2, C14.2, J8.1 (+), R17.2, U2.18 (VS), U5.18 (VS), U7.3 (Vin)
/motor_controls/standby: R31.2, U2.11 (VIO/STDBY), U5.11 (VIO/STDBY)
GND: C1.2, C3.1, C4.2, C5.2, C6.1, C8.2, C10.2 (-), C17.2, C18.2, C19.2, C20.2, J3.1 (GND), J5.1 (GND), J6.3, J6.4, J7.3, J7.4, J8.2 (-), J9.3, J11.A1_B12 (GND_A), J11.B1_A12 (GND_B), J12.5, J12.S1 (SHIELD), J12.S2 (SHIELD__1), J13.5, J13.S1 (SHIELD), J13.S2 (SHIELD__1), R3.1, R4.1, R5.1, R6.1, R7.1, R8.1, R9.1, R10.1, R11.1, R12.1, R13.1, R14.1, R18.1, R22.2, R23.1, R24.1, R32.2, R33.2, U1.1 (GND), U1.40 (GND), U1.41 (GND), U2.8 (GND), U2.9 (GND), U2.14 (GND), U2.16 (BRUV), U2.20 (BRW), U2.21 (PAD), U3.4 (GND), U4.4 (GND), U5.8 (GND), U5.9 (GND), U5.14 (GND), U5.16 (BRUV), U5.20 (BRW), U5.21 (PAD), U6.1 (adj), U7.1 (GND)
unnamed: C9.2, C11.2, C12.1, C13.1, C14.1
unnamed: D1.2 (A), JP1.1 (A)
unnamed: D1.1 (K), R32.1
unnamed: D2.2 (A), JP2.1 (A)
unnamed: D2.1 (K), R22.1
unnamed: D3.2 (A), JP3.1 (A)
unnamed: D3.1 (K), R33.1
unnamed: J9.6, U1.32 (MTCK/GPIO39/CLK_OUT3/SUBSPICS1)
unnamed: J9.7, U1.33 (MTDO/GPIO40/CLK_OUT2)
unnamed: J9.8, U1.34 (MTDI/GPIO41/CLK_OUT1)
unnamed: J9.9, U1.35 (MTMS/GPIO42)
unnamed: J10.1, U1.37 (U0TXD/GPIO43/CLK_OUT1)
unnamed: J10.2, U1.36 (U0RXD/GPIO44/CLK_OUT2)
unnamed: J11.A5 (CC1), R23.2
unnamed: J11.B5 (CC2), R24.2
unnamed: J11.A7 (DN1), J11.B7 (DN2), R20.2
unnamed: J11.A6 (DP1), J11.B6 (DP2), R21.2
unnamed: J6.1, J6.2, R30.2, U1.3 (EN)
unnamed: J7.1, J7.2, R25.2, U1.27 (GPIO0/BOOT)
unnamed: U2.13 (1.8v_out), U4.5 (ref_1), U4.6 (ref_2)
unnamed: R16.1, U2.15 (U), U4.8 (in-2)
unnamed: J1.2, U2.17 (V)
unnamed: C7.1, U2.2 (VCP)
unnamed: R15.1, U2.1 (W), U4.2 (in-1)
unnamed: J2.1, R1.2, U3.3 (in+1)
unnamed: J2.3, R2.2, U3.7 (in+2)
unnamed: R1.1, U3.2 (in-1), U5.1 (W)
unnamed: R2.1, U3.8 (in-2), U5.15 (U)
unnamed: U3.5 (ref_1), U3.6 (ref_2), U5.13 (1.8v_out)
unnamed: J1.1, R15.2, U4.3 (in+1)
unnamed: J1.3, R16.2, U4.7 (in+2)
unnamed: J2.2, U5.17 (V)
unnamed: C2.1, U5.2 (VCP)
unnamed: R17.1, U7.5 (EN)
unnamed: C15.1, L1.2, U7.2 (SW)
unnamed: C15.2, U7.6 (VBST)
unnamed: C16.2, R18.2, R19.2, U7.4 (VFB)
enc_scl: J12.2, J13.2, R26.2, U1.29 (SPIIO7/GPIO36/FSPICLK/SUBSPICLK)
enc_sda: J12.3, J13.3, R27.2, U1.28 (SPIIO6/GPIO35/FSPID/SUBSPID)
gpio38: J9.5, JP2.2 (B), U1.31 (GPIO38/FSPIWP/SUBSPIWP)
gpio47: J9.4, U1.24 (GPIO47/SPICLK_P/SUBSPICLK_P_DIFF)
m1_current_sense_u: U1.7 (GPIO7/TOUCH7/ADC1_CH6), U4.1 (out_1)
m1_current_sense_w: U1.4 (GPIO4/TOUCH4/ADC1_CH3), U4.9 (out_2)
m1_enc_cs: J13.1, U1.30 (SPIDQS/GPIO37/FSPIQ/SUBSPIQ)
m1_uh: R9.2, U1.11 (GPIO18/U1RXD/ADC2_CH7/CLK_OUT3), U2.3 (UH)
m1_ul: R5.2, U1.8 (GPIO15/U0RTS/ADC2_CH4/XTAL_32K_P), U2.6 (UL)
m1_vh: R7.2, U1.10 (GPIO17/U1TXD/ADC2_CH6), U2.4 (VH)
m1_vl: R10.2, U1.5 (GPIO5/TOUCH5/ADC1_CH4), U2.10 (VL)
m1_wh: R12.2, U1.9 (GPIO16/U0CTS/ADC2_CH5/XTAL_32K_N), U2.5 (WH)
m1_wl: R14.2, U1.6 (GPIO6/TOUCH6/ADC1_CH5), U2.7 (WL)
m2_current_sense_u: U1.12 (GPIO8/TOUCH8/ADC1_CH7/SUBSPICS1), U3.9 (out_2)
m2_current_sense_w: U1.20 (GPIO12/TOUCH12/ADC2_CH1/FSPICLK/FSPIIO6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), U3.1 (out_1)
m2_enc_cs: J12.1, U1.25 (GPIO48/SPICLK_N/SUBSPICLK_N_DIFF)
m2_uh: R3.2, U1.17 (GPIO9/TOUCH9/ADC1_CH8/FSPIHD/SUBSPIHD), U5.3 (UH)
m2_ul: R4.2, U1.21 (GPIO13/TOUCH13/ADC2_CH2/FSPIQ/FSPIIO7/S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), U5.6 (UL)
m2_vh: R6.2, U1.18 (GPIO10/TOUCH10/ADC1_CH9/FSPICS0/FSPIIO4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), U5.4 (VH)
m2_vl: R8.2, U1.23 (GPIO21), U5.10 (VL)
m2_wh: R11.2, U1.19 (GPIO11/TOUCH11/ADC2_CH0/FSPID/FSPIIO5/S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), U5.5 (WH)
m2_wl: R13.2, U1.22 (GPIO14/TOUCH14/ADC2_CH3/FSPIWP/FSPIDQS/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), U5.7 (WL)
scl: J3.4 (SCL), J5.4 (SCL), R28.2, U1.39 (GPIO1/TOUCH1/ADC1_CH0)
sda: J3.3 (SDA), J5.3 (SDA), R29.2, U1.38 (GPIO2/TOUCH2/ADC1_CH1)
usb_d+: C19.1, R21.1, U1.14 (GPIO20/U1CTS/ADC2_CH9/CLK_OUT1/USB_D+)
usb_d-: C20.1, R20.1, U1.13 (GPIO19/U1RTS/ADC2_CH8/CLK_OUT2/USB_D-)

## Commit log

2023-12-05 first commit big unfiltered dump
    [mini_MotorGo.kicad_sch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]
2023-12-05 adding v1.3 files to repo
    [mini_motor_go_V1_rev3.kicad_pcb]
2023-12-07 slight update to part selection table
    [mini_motor_go_V1_rev2.kicad_sch]
2023-12-07 rev3 changes
    [mini_motor_go_V1_rev3.kicad_sch]
2023-12-07 restructure and add .gitIgnore
    [mini_MotorGo.kicad_sch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]
2023-12-07 added part numbers and links to most parts. Ready for review. -TS
    [mini_motor_go_V1_rev3.kicad_sch, motor_go_power_system.kicad_sch, tmc6300_with_current_sense.kicad_sch]
2023-12-07 made 2 minor p/n changes
    [tmc6300_with_current_sense.kicad_sch]
2023-12-08 reviewed value table in schematics, updated footprints on board minor improvements
    [mini_motor_go_V1_rev3.kicad_pcb, mini_motor_go_V1_rev3.kicad_sch, motor_go_power_system.kicad_sch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]
2023-12-08 reverted some bad merge artifacts to working version
    [mini_motor_go_V1_rev3.kicad_sch, motor_go_power_system.kicad_sch, tmc6300_with_current_sense.kicad_sch]
2023-12-08 try to resolve differences between teams
    [mini_motor_go_V1_rev3.kicad_sch, motor_go_power_system.kicad_sch, tmc6300_with_current_sense.kicad_sch]
2023-12-08 changed .1uf caps to 0805 C14-C16
    [mini_motor_go_V1_rev3.kicad_pcb, motor_go_power_system.kicad_sch]
2023-12-08 updated part numbers for final review, compared eschema footprints to pcb file. see notes in eschema part list. TS
    [mini_motor_go_V1_rev3.kicad_sch, motor_go_power_system.kicad_sch, tmc6300_with_current_sense.kicad_sch]
2023-12-09 added gerber, centroid, and bom exports for quotes
    [mini_motor_go_V1_rev3-B_Cu.gbr, mini_motor_go_V1_rev3-B_Mask.gbr, mini_motor_go_V1_rev3-B_Paste.gbr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]
2023-12-14 updating CAD exports. TS
    [mini_motor_go_V1_rev3_BOM.xlsx]
2023-12-14 revision meeting with tom edits
    [mini_motor_go_V1_rev3.kicad_pcb, motor_go_power_system.kicad_sch, tmc6300_with_current_sense.kicad_sch]
2023-12-15 generated new design files after final engineering review. TS
    [mini_motor_go_V1_rev3-B_Cu.gbr, mini_motor_go_V1_rev3-B_Mask.gbr, mini_motor_go_V1_rev3-B_Paste.gbr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]
2024-03-27 fix indicator led silkscreen io8 to io47
    [mini_motor_go_V1_rev3.kicad_pcb, mini_motor_go_V1_rev3.kicad_sch]
2024-03-27 replace exports folder with newly generated ones since silkscreen fix
    [mini_motor_go_V1_rev3-B_Cu.gbr, mini_motor_go_V1_rev3-B_Mask.gbr, mini_motor_go_V1_rev3-B_Paste.gbr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]
2024-03-27 deleted and renamed all files
    [mini_motor_go_V1_rev2-B_Cu.gbr, mini_motor_go_V1_rev2-B_Mask.gbr, mini_motor_go_V1_rev2-B_Paste.gbr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]
2025-07-21 failed to make atopile project success
    [57.STEP, CONN-SMD_6P-P2.00_HCTL_HC-PH-6AWT.step, HVSON-8_L3.0-W3.0-H0.85-P0.65-BL-EP.step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]
2025-07-28 initial revision kicad pre-layout
    [57.STEP, CONN-SMD_6P-P2.00_HCTL_HC-PH-6AWT.step, HVSON-8_L3.0-W3.0-H0.85-P0.65-BL-EP.step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]
2025-07-28 remove unused file name
    [57.STEP, CONN-SMD_6P-P2.00_HCTL_HC-PH-6AWT.step, HVSON-8_L3.0-W3.0-H0.85-P0.65-BL-EP.step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]
2025-07-28 update motor controls schema
    [mg-gimbus-DRV8316.kicad_sch, mg-gimbus-dual-usbpd-submodule.kicad_sch, mg-gimbus.kicad_sch]
2025-07-29 incremental layout progress
    [mg-gimbus-DRV8316.kicad_sch, mg-gimbus-dual-usbpd-submodule.kicad_sch, mg-gimbus.kicad_pcb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]
2025-07-31 Ready for ordering pcb files
    [mg-gimbus-dual-usbpd-submodule.kicad_sch, mg-gimbus.kicad_pcb, mg-gimbus.kicad_sch]
2025-07-31 remove blender assets, unused
    [plastic-semi-metallic_88b62dd1-ac6d-498e-8cbc-a5dea9a39e21.blend, procedual-cloud-node-group_5a9ab3ee-915b-4d86-a1bc-005b33f1413e.blend]
